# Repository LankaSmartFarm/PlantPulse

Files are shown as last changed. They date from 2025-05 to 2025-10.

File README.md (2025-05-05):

# 🌿 PlantPulse – Universal IoT Device for Smart Agriculture

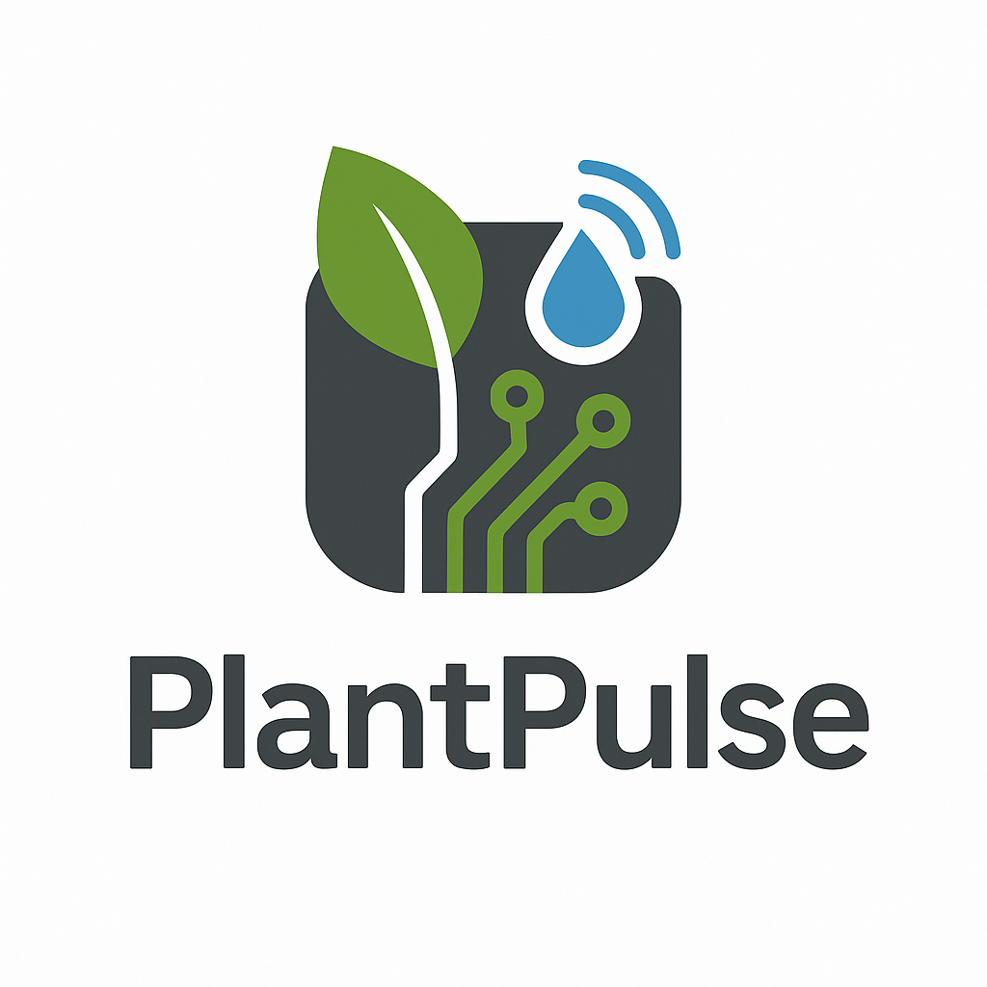
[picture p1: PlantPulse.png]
PlantPulse Logo


**PlantPulse** is an open-source, rugged, and intelligent IoT hardware platform designed as part of the LankaSmartFarm DPI initiative. It enables precision farming through sensor-driven insights and remote control, built specifically for the tropical agriculture challenges of Sri Lanka and similar regions.

This universal device combines sensing, communication, and control in a modular, scalable way—empowering farmers and AgriTech developers with real-time actionable data and automation.

---

## 🚀 Key Features

### 🌱 Sensor Suite (7-in-1 Soil Health Monitoring)
- Monitors:
  - **pH**
  - **Soil Moisture**
  - **Soil Temperature**
  - **Electrical Conductivity (EC)**
  - **Nitrogen (N)**
  - **Phosphorus (P)**
  - **Potassium (K)**  
- Periodic sensing powered by a separate 12V replaceable battery to preserve energy for critical reads.

### 🔊 Acoustic Monitoring & Alerting
- **Speaker + Microphone** for:
  - Insect repellent sound pulses
  - Audible alarms
  - Acoustic anomaly detection (under research)

### 🎯 Visual & Motion Sensing *(Research Stage)*
- Bug detection via visual traps
- Animal trespass monitoring using computer vision models or IR sensors

### 💧 Smart Irrigation & Fertigation Control
- Remotely control **drip irrigation** systems
- Activate **nutrient delivery** only when required

### 🔌 Controllable AUX & GPIO Ports
- Support for up to **10 auxiliary IOs**
- Configurable for lighting, spraying, fans, or custom actuators

---

## 🧠 Architecture

### 🌐 Central IoT Controller
- Acts as the **brain** of the PlantPulse network
- Connects to the cloud for telemetry reporting and receiving commands
- Commands child sensors dynamically—no need for hardcoded logic on each device
- Manages sensor behaviour and firmware updates centrally

### 📡 Child Sensor Nodes
- Connected via **RF or LoRa** for long-range, low-power communication
- Powered by:
  - **MCU battery** (rechargeable via compact solar panel array)
  - **12V sensing battery** for heavy sensor reads
- Contain **RGB status LEDs** for local feedback (alarm, status, fault, etc.)
- Built-in **self-check and debugging** capabilities to detect sensor connectivity or hardware faults

---

## 🛡️ Rugged Design

- **IP67-rated** enclosure
- Engineered to survive:
  - Tropical humidity
  - Heavy rainfall
  - High UV exposure
  - Impacts from falling fruits like coconuts or mangoes
- Can be securely fixed to the ground

---

## 🔧 Open Hardware Goals

PlantPulse aims to be:
- Fully **open-source** (hardware schematics + firmware)
- Modular and extensible
- Built using off-the-shelf components wherever possible
- Maintainable and upgradeable in the field with **no need for full reprogramming**

---

## 🌍 Why It Matters

- **Reduces manual labour and guesswork** in plantation and field farming
- **Supports climate-resilient agriculture** by providing precise micro-level insights
- **Scales easily** from backyard farms to large estates
- Aligns with **Digital Public Infrastructure (DPI)** and **DPG** principles

---

## 🧩 Project Status

- ✅ Hardware architecture and component design – In Progress  
- ⚙️ Firmware development – Early Stage  
- 📶 Communication protocol – RF/LoRa planned  
- 🔬 Bug and trespass detection – Research stage  
- 🔋 Solar & battery power testing – Prototyping  

Stay tuned for schematics, BOM, and reference firmware.

---

## 🤝 Contributing

We welcome hardware tinkerers, firmware developers, Agri researchers, and field testers.

Check our [CONTRIBUTING.md](CONTRIBUTING.md) to get started.

---

## 📜 License

This project will be released under an open hardware-compliant license (e.g., CERN-OHL or Solderpad License). Final terms TBA.

---

## 📬 Contact & Updates

- 🌐 [LankaSmartFarm GitHub](https://github.com/LankaSmartFarm)

---

> “Data grows when rooted in the soil. PlantPulse makes the invisible visible — one sensor at a time.”

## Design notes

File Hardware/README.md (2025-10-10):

# 🌿 Plant Pulse Hardware V1.0 (PCB)

### Featuring **ESP32-S3**

---

## 🧩 Overview
**Plant Pulse Hardware V1.0** is a custom-designed PCB built around the powerful **ESP32-S3** microcontroller.  
It is designed to monitor and analyze plant health and environmental conditions using advanced sensors and smart communication protocols.

---

## ⚙️ Key Features
- 🌱 **ESP32-S3** for Wi-Fi and Bluetooth connectivity  
- 🌾 **7-in-1 Soil Sensor Interface** for measuring multiple soil parameters  
- 🔄 **RS485 Modbus Communication** support for reliable industrial sensor interfacing  
- 🔋 **3.7V Li-ion Battery** operation for portable applications  
- 🔌 **USB Type-C Charging** for easy power management  

---

## 🔧 Hardware Highlights
| Component | Description |
|---|---|
| **MCU** | ESP32-S3 |
| **Sensor Interface** | 7-in-1 Soil Sensor via UART/RS485 |
| **Communication Protocol** | Modbus RTU |
| **Power Source** | 3.7V Li-ion Battery |
| **Charging Port** | USB Type-C |
| **Regulators & Protection** | Integrated battery protection and voltage regulation |

---

## 🪛 Applications
- Smart Agriculture 🌾  
- IoT-Based Plant Monitoring 🌿  
- Greenhouse Automation 🌼  
- Environmental Data Logging ☀️  

---

## 📘 Version Information
- **Version:** 1.0  
- **Type:** PCB Hardware Design  
- **Status:** Prototype/Testing Phase  

---

## 🧠 Future Improvements
- Onboard display (OLED/TFT) for real-time readings  
- Power optimization for long-term field deployment  

---

## 🖼️ Preview
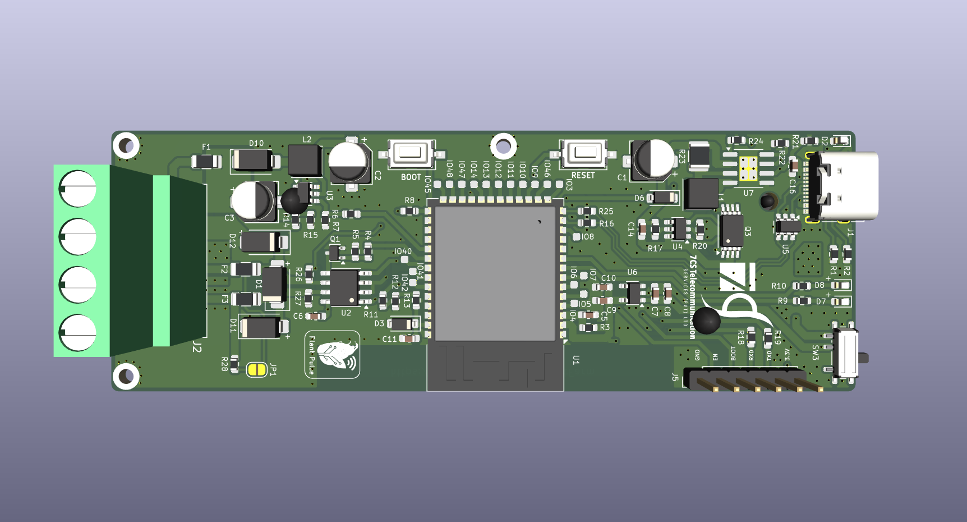
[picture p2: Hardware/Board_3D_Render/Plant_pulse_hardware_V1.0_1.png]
Plant Pulse PCB Top View

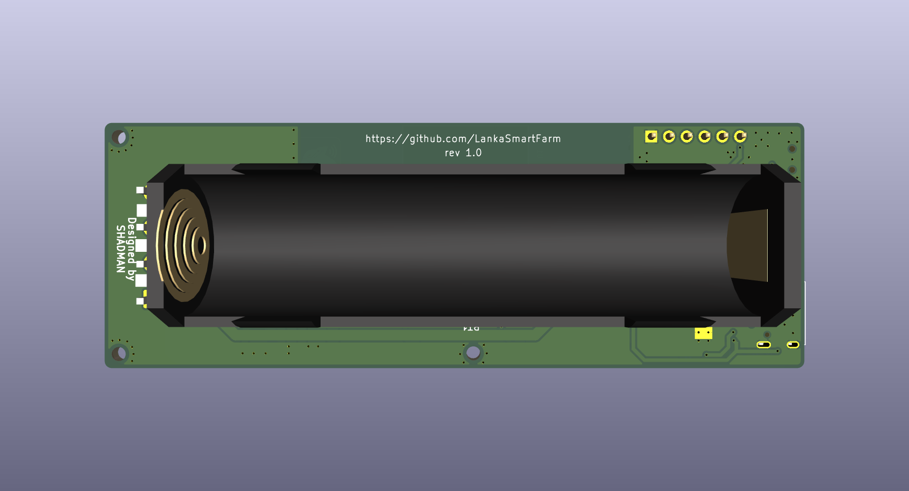
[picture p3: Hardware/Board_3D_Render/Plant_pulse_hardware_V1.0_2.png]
Plant Pulse PCB Bottom View

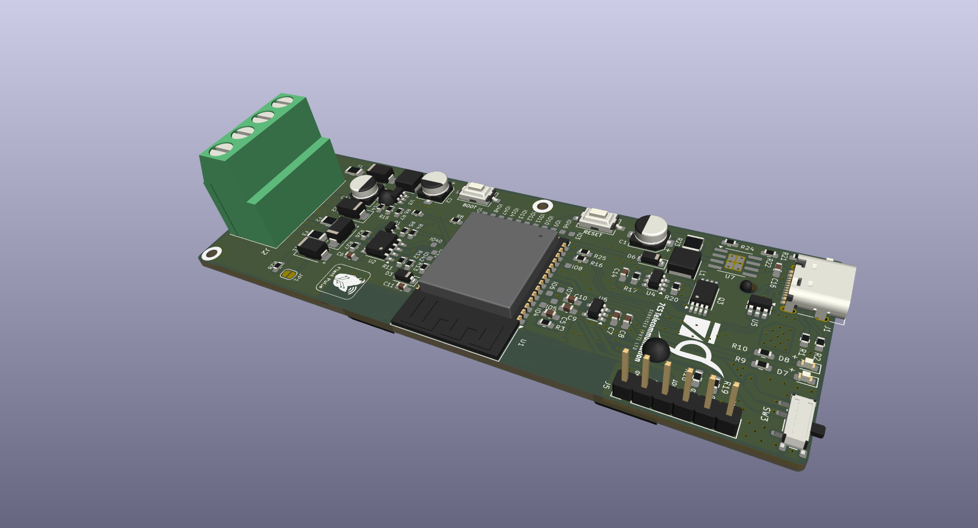
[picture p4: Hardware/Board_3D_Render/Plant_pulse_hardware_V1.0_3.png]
Plant Pulse PCB Side View

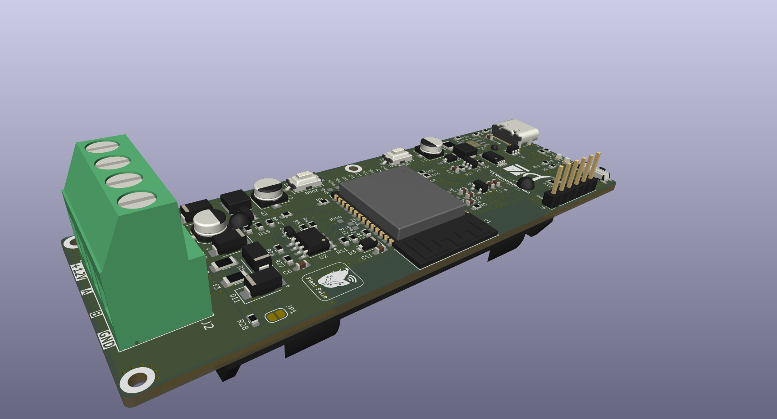
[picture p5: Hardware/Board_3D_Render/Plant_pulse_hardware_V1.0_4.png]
Plant Pulse PCB Side2 View


```bash
📁 /PlantPulse_Hardware_V1.0
 ├── Gerber_Files/
 ├── Schematic PDF/
 ├── Board_3D_Render
 ├── BOM_POS/
 └── README.md

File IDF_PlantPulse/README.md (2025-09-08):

# 🌱 PlantPulse – Smart Agriculture Monitoring System  

PlantPulse is an **ESP32-based IoT device** for precision agriculture.  
It collects data from **20 Modbus soil sensors** (pH, moisture, temperature, EC, N, P, K), logs it into **FATFS**, synchronizes time with a **DS3231 RTC** and GSM network, and transmits data to the cloud over **SIM800L MQTT**.

---

## 🚀 Features  
- 📡 **MQTT over SIM800L GSM** (custom lightweight MQTT client)  
- 🧪 **20 Soil Sensors** via RS485 Modbus  
- 🕒 **Timekeeping with DS3231 RTC** (synced with GSM time if drift >10s)  
- 💾 **Data Logging with FATFS** (binary files, timestamped filenames)  
- 🔄 **Auto Reconnect** for GSM & MQTT  
- 🗑️ **Reliable Storage** – if publish fails, payload is stored in FATFS and re-sent later  
- 🔌 **Custom ESP-IDF Components** (MQTT, RTC, RS485, FATFS)  

---

## 🔌 Hardware Pinout  

| Peripheral | ESP32 Pin | Notes |
|---|---|---|
| **SIM800L GSM** | | |
| TX (SIM800L → ESP32 RX) | GPIO15 | UART1 RX (ESP32 receives) |
| RX (SIM800L ← ESP32 TX) | GPIO16 | UART1 TX (ESP32 transmits) |
| RESET | GPIO3 | SIM800L reset control |
| **RTC DS3231** | | |
| I2C SDA | GPIO4 | I2C data line |
| I2C SCL | GPIO5 | I2C clock line |
| INT/SQW | GPIO6 | RTC interrupt / square wave output  |
| **RS485 Modbus** | | |
| RX | GPIO17 | UART RX for Modbus slave |
| TX | GPIO18 | UART TX for Modbus master |

*(Update pins as per your final design)*  

---

## 📡 Protocols  

- **MQTT (Custom Lightweight Client over GSM AT commands)**  
- **Modbus RTU** (RS485 multi-drop for soil sensors)  
- **FATFS** (SPI Flash storage for logs & credentials)  
- **I2C** (RTC DS3231 time sync)  

---

## 📂 File Structure  

├── components/ # Custom ESP-IDF components
│ ├── mqtt/ # SIM800L MQTT client
│ ├── myRtc/ # DS3231 RTC driver
│ └── RS_485/ # Modbus RS485 driver
├── main/ # Application code
│ ├── storage/ # FATFS storage handling
│ │ ├── FS.c
│ │ └── FS.h
│ ├── dataLogging.c # Logging logic
│ ├── dataLogging.h
│ ├── main.c # Main application entry point
│ └── CMakeLists.txt
├── partitions.csv # Flash partition table
├── CMakeLists.txt # Project CMake

---

## ⚡ Build & Flash Instructions  

```bash
# Clone repo
git clone https://github.com/yourusername/PlantPulse.git
cd PlantPulse

# Set ESP-IDF environment
. $HOME/esp/esp-idf/export.sh

# Build
idf.py build

# Flash
idf.py -p /dev/ttyUSB0 flash

# Monitor
idf.py monitor

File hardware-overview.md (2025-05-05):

# 🔩 PlantPulse Hardware Overview

This document outlines the hardware architecture and component design of the **PlantPulse** universal smart farming IoT device.

---

## 📦 System Architecture

### 🧠 Central IoT Controller

- **Role**: Central command unit for all child sensor nodes
- **Responsibilities**:
  - Connects to the cloud (Wi-Fi/4G/LTE)
  - Receives commands from cloud services
  - Sends telemetry data (sensor readings, device health)
  - Dispatches control signals to child sensor nodes
- **Features**:
  - Local command queuing and scheduling
  - Minimal power consumption with sleep cycles
  - Modular firmware upgradable remotely

### 🌿 Child Sensor Nodes (Field Units)

- **Communication**: RF/LoRa modules (up to 1–2 km LOS)
- **Power System**:
  - Rechargeable battery (MCU operation)
  - 12V replaceable battery (for 7-in-1 sensing only)
  - Solar charging system (4x calculator-sized panels)
- **Indicators**: RGB LED for:
  - Alarms
  - Sensor health
  - Activity indication
- **Self-diagnostics**: Sensor connection and health checks

---

## 🧪 Sensor Suite

### 🔬 7-in-1 Soil Quality Sensor

- pH
- Soil Moisture
- Soil Temperature
- Electrical Conductivity (EC)
- Nitrogen (N)
- Phosphorus (P)
- Potassium (K)

### 🔊 Acoustic Subsystem

- **Microphone**: Insect detection, environmental sound capture
- **Speaker**: Alarm output, sound-based repellent (experimental)

### 👀 Visual Detection *(Under Research)*

- Bug trap imaging and recognition
- Animal trespass detection using camera module + CV

---

## 🔌 AUX & GPIO Expansion

- **Up to 10 GPIOs** for:
  - Relays
  - Pumps
  - Lights
  - External devices
- Fully configurable via central controller commands

---

## 🛡️ Enclosure & Protection

- **IP67-rated** shell
- Designed to resist:
  - Rain, humidity, and heat
  - Impact from falling fruits (e.g., coconuts, mangoes)
  - Ground vibrations and animals
- Ground-anchorable

---

## 🧩 Component Sourcing

- Off-the-shelf modules where possible
- Open schematics and BOM to be published

---

## 🗺️ Deployment Topologies

- **Standalone Node**: Single unit operation for isolated crops
- **Cluster Mode**: One central controller managing up to 50+ nodes
- **Mesh Expansion**: Planned support for mesh networking in Phase 2

---

> Want to help with circuit design or PCB layout? Start a discussion or open an issue!

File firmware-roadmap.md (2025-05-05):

# 🧠 PlantPulse Firmware Roadmap

This document outlines the development plan for firmware modules across the PlantPulse IoT system.

---

## 🏗️ Architecture

### Firmware Layers:

1. **Device Abstraction Layer (DAL)**  
   - Interfaces directly with sensors, IOs, and power modules

2. **Control Logic Layer**  
   - Executes scheduled actions
   - Interprets central controller commands
   - Handles local events and diagnostics

3. **Communication Layer**  
   - RF/LoRa communication protocol
   - Data encryption & compression
   - OTA firmware update protocol (planned)

4. **Telemetry Layer**  
   - Formats and sends telemetry to central controller
   - Includes timestamps, battery, sensor data, and faults

---

## 📅 Roadmap

### 🔹 Phase 1 – MVP (Q2 2025)
- [x] Basic GPIO toggling from central controller
- [x] Periodic sensor reading
- [x] RGB LED status indicators
- [ ] Basic telemetry reporting
- [ ] Manual reset + debug mode

### 🔸 Phase 2 – Core Features (Q3 2025)
- [ ] LoRa mesh node discovery
- [ ] Event-driven triggers (e.g., moisture too low → activate pump)
- [ ] OTA firmware updates
- [ ] Self-diagnostics on sensor health

### 🔹 Phase 3 – Advanced Intelligence (Q4 2025)
- [ ] AI-assisted edge logic (soil condition learning)
- [ ] Audio event pattern detection
- [ ] Vision-based bug/animal detection (if module available)

---

## 🛠 Development Notes

- Written in C/C++ (Arduino/PlatformIO base)
- Open to MicroPython and Rust prototypes
- GitHub Actions CI for unit testing
- Separate branches for stable vs. experimental firmware

---

> Contributions welcome for modular drivers, LoRa protocol enhancements, or data compression techniques.

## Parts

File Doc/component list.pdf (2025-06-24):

## List of Components

SN | Name | Quantity
1 | ESP32-S3 N16R8 | 2
2 | TTL to RS-485 | 2
3 | 7in 1 Sensor | 2
4 | USB Type-C Cable | 2
5 | USB to RS-485 Converter | 1
6 | 12V Battery pack | 1
7 | Lora( SX1278)+ Atenna | 2
8 | GSM Module SIM800L or SIM800C | 1
9 | Antenna | 2
10 | Buck Converter | 3
11 | Led Multiple Color | 20
12 | Power Supply 12v | 1
13 | Some wire | As needed
14 | Male/Female jumper wire (good Quality) | As needed
15 | Power Switch | 3
16 | 4 Chanel Relay | 2
17 | DS1307 RTC module | 1
18 | RTC Battery | 2
19 | Glugan, glustic | 1
20 | Bero board | 3
21 | Male Header | As needed
22 | Resistor | 1k, 330, 10k
23 | Push Button Switch | 5

2 4 | C a p a cit o r | 1 0, 2 0, 5 0, 1 5,1 0 0 m
| Insulation tape Plastic box | 1 26 To keep all materials f, 25

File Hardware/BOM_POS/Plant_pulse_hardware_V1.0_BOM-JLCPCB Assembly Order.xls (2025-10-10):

JLCPCB BOM Tool - BOM Matching
BOM name：Plant_pulse_hardware_V1.0_BOM-JLCPCB Assembly Order.xlsx |  |  | Download Time：2025-10-04 22:56:29 |  |  |  | * Our matching results are updated in real-time, but stock and prices may change. If it's been over 24 hours, please re-match before placing your order.
PCB Assembled Qty：10 |  |  | Est. Total Price：28.1363
Your BOM |  |  |  |  | Matched Parts |  |  |  |  |  |  | Order Information
Top Designator | Bottom Designator | Comment | Footprint | JLCPCB Part # | Matches | Part # | Manufacturer | Footprint | Description | Category | Warning | JLCPCB Part # | Product link | Lib Type | Qty | Source | Total Price ($)
C1 |  | 220uf/35V | Capacitor_SMD:CP_Elec_5x3 |  | Select by System | RVT1C220M0505 22UF 16V | DMBJ | SMD,D5xL5.4mm | -55℃~+105℃ 16V 22uF 2800hrs@105℃ 28mA@120Hz 5.4mm 5mm ±20% SMD,D5xL5.4mm Aluminum Electrolytic Capacitors - SMD ROHS | Aluminum Electrolytic Capacitors - SMD |  | C970662 | https://jlcpcb.com/partdetail/DMBJ-RVT1C220M0505_22UF16V/C970662 | Extended | 34 | 34 JLCPCB | 0.9452
C2 |  | 220uf/35V | Capacitor_SMD:CP_Elec_5x3 |  | Select by System | RVT1C220M0505 22UF 16V | DMBJ | SMD,D5xL5.4mm | -55℃~+105℃ 16V 22uF 2800hrs@105℃ 28mA@120Hz 5.4mm 5mm ±20% SMD,D5xL5.4mm Aluminum Electrolytic Capacitors - SMD ROHS | Aluminum Electrolytic Capacitors - SMD |  | C970662 | https://jlcpcb.com/partdetail/DMBJ-RVT1C220M0505_22UF16V/C970662 | Extended | 34 | 34 JLCPCB | 0.9452
C3 |  | 220uf/35V | Capacitor_SMD:CP_Elec_5x3 |  | Select by System | RVT1C220M0505 22UF 16V | DMBJ | SMD,D5xL5.4mm | -55℃~+105℃ 16V 22uF 2800hrs@105℃ 28mA@120Hz 5.4mm 5mm ±20% SMD,D5xL5.4mm Aluminum Electrolytic Capacitors - SMD ROHS | Aluminum Electrolytic Capacitors - SMD |  | C970662 | https://jlcpcb.com/partdetail/DMBJ-RVT1C220M0505_22UF16V/C970662 | Extended | 34 | 34 JLCPCB | 0.9452
C5 |  | 1uf/16V | Capacitor_SMD:C_0603_1608Metric_Pad1.08x0.95mm_HandSolder |  | Select by System | CL10A105KB8NNNC | Samsung Electro-Mechanics | 0603 | 1uF 50V X5R ±10% 0603 Multilayer Ceramic Capacitors MLCC - SMD/SMT ROHS | Multilayer Ceramic Capacitors MLCC - SMD/SMT |  | C15849 | https://jlcpcb.com/partdetail/16531-CL10A105KB8NNNC/C15849 | Basic | 10 | 10 JLCPCB | 0.047
C6 |  | 100nf/50V | Capacitor_SMD:C_0603_1608Metric_Pad1.08x0.95mm_HandSolder |  | Select by System | CC0603KRX7R9BB104 | YAGEO | 0603 | 100nF 50V X7R ±10% 0603 Multilayer Ceramic Capacitors MLCC - SMD/SMT ROHS | Multilayer Ceramic Capacitors MLCC - SMD/SMT |  | C14663 | https://jlcpcb.com/partdetail/YAGEO-CC0603KRX7R9BB104/C14663 | Basic | 50 | 50 JLCPCB | 0.115
C8 |  | 100nf/50V | Capacitor_SMD:C_0603_1608Metric_Pad1.08x0.95mm_HandSolder |  | Select by System | CC0603KRX7R9BB104 | YAGEO | 0603 | 100nF 50V X7R ±10% 0603 Multilayer Ceramic Capacitors MLCC - SMD/SMT ROHS | Multilayer Ceramic Capacitors MLCC - SMD/SMT |  | C14663 | https://jlcpcb.com/partdetail/YAGEO-CC0603KRX7R9BB104/C14663 | Basic | 50 | 50 JLCPCB | 0.115
C9 |  | 100nf/50V | Capacitor_SMD:C_0603_1608Metric_Pad1.08x0.95mm_HandSolder |  | Select by System | CC0603KRX7R9BB104 | YAGEO | 0603 | 100nF 50V X7R ±10% 0603 Multilayer Ceramic Capacitors MLCC - SMD/SMT ROHS | Multilayer Ceramic Capacitors MLCC - SMD/SMT |  | C14663 | https://jlcpcb.com/partdetail/YAGEO-CC0603KRX7R9BB104/C14663 | Basic | 50 | 50 JLCPCB | 0.115
C11 |  | 100nf/50V | Capacitor_SMD:C_0603_1608Metric_Pad1.08x0.95mm_HandSolder |  | Select by System | CC0603KRX7R9BB104 | YAGEO | 0603 | 100nF 50V X7R ±10% 0603 Multilayer Ceramic Capacitors MLCC - SMD/SMT ROHS | Multilayer Ceramic Capacitors MLCC - SMD/SMT |  | C14663 | https://jlcpcb.com/partdetail/YAGEO-CC0603KRX7R9BB104/C14663 | Basic | 50 | 50 JLCPCB | 0.115
C14 |  | 100nf/50V | Capacitor_SMD:C_0603_1608Metric_Pad1.08x0.95mm_HandSolder |  | Select by System | CC0603KRX7R9BB104 | YAGEO | 0603 | 100nF 50V X7R ±10% 0603 Multilayer Ceramic Capacitors MLCC - SMD/SMT ROHS | Multilayer Ceramic Capacitors MLCC - SMD/SMT |  | C14663 | https://jlcpcb.com/partdetail/YAGEO-CC0603KRX7R9BB104/C14663 | Basic | 50 | 50 JLCPCB | 0.115
C7 |  | 10uf/50V | Capacitor_SMD:C_0603_1608Metric_Pad1.08x0.95mm_HandSolder |  | Select by Customer | CL10A106KP8NNNC | Samsung Electro-Mechanics | 0603 | 10V 10uF X5R ±10% 0603 Multilayer Ceramic Capacitors MLCC - SMD/SMT ROHS | Multilayer Ceramic Capacitors MLCC - SMD/SMT |  | C19702 | https://jlcpcb.com/partdetail/20411-CL10A106KP8NNNC/C19702 | Basic | 30 | 30 JLCPCB | 0.168
C10 |  | 10uf/50V | Capacitor_SMD:C_0603_1608Metric_Pad1.08x0.95mm_HandSolder |  | Select by Customer | CL10A106KP8NNNC | Samsung Electro-Mechanics | 0603 | 10V 10uF X5R ±10% 0603 Multilayer Ceramic Capacitors MLCC - SMD/SMT ROHS | Multilayer Ceramic Capacitors MLCC - SMD/SMT |  | C19702 | https://jlcpcb.com/partdetail/20411-CL10A106KP8NNNC/C19702 | Basic | 30 | 30 JLCPCB | 0.168
C16 |  | 10uf/50V | Capacitor_SMD:C_0603_1608Metric_Pad1.08x0.95mm_HandSolder |  | Select by Customer | CL10A106KP8NNNC | Samsung Electro-Mechanics | 0603 | 10V 10uF X5R ±10% 0603 Multilayer Ceramic Capacitors MLCC - SMD/SMT ROHS | Multilayer Ceramic Capacitors MLCC - SMD/SMT |  | C19702 | https://jlcpcb.com/partdetail/20411-CL10A106KP8NNNC/C19702 | Basic | 30 | 30 JLCPCB | 0.168
D1 |  | SMAJ6.8CA | Diode_SMD:D_SMA |  | Select by System | SMAJ6.8CA | FUXINSEMI | DO-214AC(SMA) | 10.5V 1mA 39A 400W 5.8V 7.14V Bidirectional TVS DO-214AC(SMA) ESD and Surge Protection (TVS/ESD) ROHS | ESD And Surge Protection (TVS/ESD) |  | C5380696 | https://jlcpcb.com/partdetail/FUXINSEMI-SMAJ68CA/C5380696 | Extended | 38 | 38 JLCPCB | 1.2198
D11 |  | SMAJ6.8CA | Diode_SMD:D_SMA |  | Select by System | SMAJ6.8CA | FUXINSEMI | DO-214AC(SMA) | 10.5V 1mA 39A 400W 5.8V 7.14V Bidirectional TVS DO-214AC(SMA) ESD and Surge Protection (TVS/ESD) ROHS | ESD And Surge Protection (TVS/ESD) |  | C5380696 | https://jlcpcb.com/partdetail/FUXINSEMI-SMAJ68CA/C5380696 | Extended | 38 | 38 JLCPCB | 1.2198
D12 |  | SMAJ6.8CA | Diode_SMD:D_SMA |  | Select by System | SMAJ6.8CA | FUXINSEMI | DO-214AC(SMA) | 10.5V 1mA 39A 400W 5.8V 7.14V Bidirectional TVS DO-214AC(SMA) ESD and Surge Protection (TVS/ESD) ROHS | ESD And Surge Protection (TVS/ESD) |  | C5380696 | https://jlcpcb.com/partdetail/FUXINSEMI-SMAJ68CA/C5380696 | Extended | 38 | 38 JLCPCB | 1.2198
D2 |  | LED_RED | LED_SMD:LED_0603_1608Metric |  | Select by System | YLED0805R | YONGYUTAI | 0805 | -40℃~+85℃ 1.8V~2.4V 120mcd 120° 20mA 60mW 615nm~630nm 645nm Red 0805 LED Indication - Discrete ROHS | LED Indication - Discrete |  | C19171391 | https://jlcpcb.com/partdetail/YONGYUTAI-YLED0805R/C19171391 | Extended | 20 | 20 JLCPCB | 0.142
D6 |  | 1N4148W | Diode_SMD:D_SOD-123 |  | Select by System | 1N4148W-7-F | Diodes Incorporated | SOD-123 | -65℃~+150℃@(Tj) 1.25V@150mA 100V 1uA@75V 300mA 4ns Independent SOD-123 Switching Diodes ROHS | Switching Diodes |  | C83528 | https://jlcpcb.com/partdetail/DiodesIncorporated-1N4148W_7F/C83528 | Extended | 20 | 20 JLCPCB | 0.31
D7 |  | LED_GERRN | LED_SMD:LED_0603_1608Metric |  | Unconfirmed | KT-0603R | Hubei KENTO Elec | 0603 | -40℃~+85℃ 120° 2.4V 20mA 300mcd 40mW 615nm~630nm 645nm Red Water Clear 0603 LED Indication - Discrete ROHS | LED Indication - Discrete | 1.The comment (KT-0603R) of this part does not match the one (LED_GERRN) provided in your BOM. Please confirm; | C2286 | https://jlcpcb.com/partdetail/Hubei_KENTOElec-KT0603R/C2286 | Basic | 0 | 0 JLCPCB | 0
D8 |  | LED_BLUE | LED_SMD:LED_0603_1608Metric |  | Select by System | LTST-C191TBKT | Lite-On | 0603 | -20℃~+80℃ 104mcd 130° 20mA 3.3V 465nm~475nm 468nm 75mW Blue Water Clear 0603 LED Indication - Discrete ROHS | LED Indication - Discrete |  | C99290 | https://jlcpcb.com/partdetail/LiteOn-LTSTC191TBKT/C99290 | Extended | 20 | 20 JLCPCB | 0.382
D9 |  | BZM55B3V3-TR | Diode_SMD:D_MicroMELF |  | Select by Customer | ZMM3V3 | Slkor(SLKORMICRO Elec.) | LL-34 | 2uA 3.1V~3.5V 3.3V 500mW 600Ω 85Ω Independent LL-34 Zener Diodes ROHS | Zener Diodes |  | C707189 | https://jlcpcb.com/partdetail/Slkor_SLKORMICRO_Elec-ZMM3V3/C707189 | Extended | 20 | 20 JLCPCB | 0.174
D10 |  | SS34 | Diode_SMD:D_SMA |  | Select by System | SS34 | MDD(Microdiode Semiconductor) | SMA(DO-214AC) | -55℃~+125℃ 3A 40V 500uA@40V 550mV@3A Independent SMA(DO-214AC) Schottky Diodes ROHS | Schottky Diodes |  | C8678 | https://jlcpcb.com/partdetail/MDD_Microdiode_Semiconductor-SS34/C8678 | Basic | 10 | 10 JLCPCB | 0.276
F1 |  | 0468001.NRHF | Fuse:Fuse_1206_3216Metric |  | Select by System | 0468001.NRHF | Littelfuse | 1206 | -55℃~+90℃ 1A 50A 63V Surface Mount Fuse 1206 Disposable fuses ROHS | Disposable Fuses |  | C45157 | https://jlcpcb.com/partdetail/Littelfuse-0468001NRHF/C45157 | Extended | 12 | 12 JLCPCB | 0.756
F2 |  | BSMD1206C-0250T | Fuse:Fuse_1206_3216Metric |  | Select by System | BSMD1206C-0250T | BHFUSE | 1206 | -55℃~+150℃ 0.00043 250mA 50A 72V 72V Surface Mount Fuse 1206 Disposable fuses ROHS | Disposable Fuses |  | C41398508 | https://jlcpcb.com/partdetail/BHFUSE-BSMD1206C0250T/C41398508 | Extended | 24 | 24 JLCPCB | 1.8768
F3 |  | BSMD1206C-0250T | Fuse:Fuse_1206_3216Metric |  | Select by System | BSMD1206C-0250T | BHFUSE | 1206 | -55℃~+150℃ 0.00043 250mA 50A 72V 72V Surface Mount Fuse 1206 Disposable fuses ROHS | Disposable Fuses |  | C41398508 | https://jlcpcb.com/partdetail/BHFUSE-BSMD1206C0250T/C41398508 | Extended | 24 | 24 JLCPCB | 1.8768
J1 |  | USB_C_Receptacle_USB2.0_16P | Connector_USB:USB_C_Receptacle_G-Switch_GT-USB-7010ASV |  | Select by System | TYPE-C 16PIN 2MD(073) | SHOU HAN | SMD | -25℃~+85℃ 1 16P 3A 5,000 Cycles 5V Black Female Surface Mount, Right Angle Type-C SMD USB Connectors ROHS | USB Connectors |  | C2765186 | https://jlcpcb.com/partdetail/SHOUHAN-TYPE_C_16PIN_2MD_073/C2765186 | Extended | 11 | 11 JLCPCB | 0.6193
L1 |  | 4.7uh | Inductor_SMD:L_Changjiang_FNR4020S |  | Select by System | FNR4020S4R7MT | cjiang (Changjiang Microelectronics Tech) | SMD,4x4mm | 2.5A 2A 4.7uH 98mΩ Magnetic Shielded Inductor ±20% SMD,4x4mm Power Inductors ROHS | Power Inductors |  | C167828 | https://jlcpcb.com/partdetail/179211-FNR4020S4R7MT/C167828 | Extended | 24 | 24 JLCPCB | 1.1352
L2 |  | 4.7uh | Inductor_SMD:L_Changjiang_FNR4020S |  | Select by System | FNR4020S4R7MT | cjiang (Changjiang Microelectronics Tech) | SMD,4x4mm | 2.5A 2A 4.7uH 98mΩ Magnetic Shielded Inductor ±20% SMD,4x4mm Power Inductors ROHS | Power Inductors |  | C167828 | https://jlcpcb.com/partdetail/179211-FNR4020S4R7MT/C167828 | Extended | 24 | 24 JLCPCB | 1.1352
Q1 |  | Si1308EDL | Package_TO_SOT_SMD:SOT-323_SC-70 |  | Select by System | SI1308EDL | TECH PUBLIC | SOT-323 | -55℃~+150℃ 1.4A 1.5V 14.8pF@15V 146pF@15V 150mΩ@4.5V,0.5A 30V 360mW SOT-323 MOSFETs ROHS | MOSFETs |  | C7603347 | https://jlcpcb.com/partdetail/TECHPUBLIC-SI1308EDL/C7603347 | Extended | 14 | 14 JLCPCB | 0.8274
Q3 |  | FS8205A | Package_SO:TSSOP-8_4.4x3mm_P0.65mm |  | Select by System | 8205A | HXY MOSFET | TSSOP-8 | -55℃~+150℃ 1.5W 140pF 15nC@4.5V 2 N-Channel 20V 37mΩ@2.5V,3.5A 500mV 600pF 6A TSSOP-8 MOSFETs ROHS | MOSFETs |  | C5148694 | https://jlcpcb.com/partdetail/HXYMOSFET-8205A/C5148694 | Extended | 14 | 14 JLCPCB | 0.756
R1 |  | 5.1K | Resistor_SMD:R_0603_1608Metric |  | Unconfirmed | 0603WAF5101T5E | UNI-ROYAL(Uniroyal Elec) | 0603 | -55℃~+155℃ 100mW 5.1kΩ 75V Thick Film Resistor ±1% ±100ppm/℃ 0603 Chip Resistor - Surface Mount ROHS | Chip Resistor - Surface Mount | 1.The comment (0603WAF5101T5E) of this part does not match the one (5.1K) provided in your BOM. Please confirm; | C23186 | https://jlcpcb.com/partdetail/23913-0603WAF5101T5E/C23186 | Basic | 0 | 0 JLCPCB | 0
R2 |  | 5.1K | Resistor_SMD:R_0603_1608Metric |  | Unconfirmed | 0603WAF5101T5E | UNI-ROYAL(Uniroyal Elec) | 0603 | -55℃~+155℃ 100mW 5.1kΩ 75V Thick Film Resistor ±1% ±100ppm/℃ 0603 Chip Resistor - Surface Mount ROHS | Chip Resistor - Surface Mount | 1.The comment (0603WAF5101T5E) of this part does not match the one (5.1K) provided in your BOM. Please confirm; | C23186 | https://jlcpcb.com/partdetail/23913-0603WAF5101T5E/C23186 | Basic | 0 | 0 JLCPCB | 0
R9 |  | 5.1K | Resistor_SMD:R_0603_1608Metric |  | Unconfirmed | 0603WAF5101T5E | UNI-ROYAL(Uniroyal Elec) | 0603 | -55℃~+155℃ 100mW 5.1kΩ 75V Thick Film Resistor ±1% ±100ppm/℃ 0603 Chip Resistor - Surface Mount ROHS | Chip Resistor - Surface Mount | 1.The comment (0603WAF5101T5E) of this part does not match the one (5.1K) provided in your BOM. Please confirm; | C23186 | https://jlcpcb.com/partdetail/23913-0603WAF5101T5E/C23186 | Basic | 0 | 0 JLCPCB | 0
R10 |  | 5.1K | Resistor_SMD:R_0603_1608Metric |  | Unconfirmed | 0603WAF5101T5E | UNI-ROYAL(Uniroyal Elec) | 0603 | -55℃~+155℃ 100mW 5.1kΩ 75V Thick Film Resistor ±1% ±100ppm/℃ 0603 Chip Resistor - Surface Mount ROHS | Chip Resistor - Surface Mount | 1.The comment (0603WAF5101T5E) of this part does not match the one (5.1K) provided in your BOM. Please confirm; | C23186 | https://jlcpcb.com/partdetail/23913-0603WAF5101T5E/C23186 | Basic | 0 | 0 JLCPCB | 0
R3 |  | 10K | Resistor_SMD:R_0603_1608Metric |  | Unconfirmed | 0603WAF1002T5E | UNI-ROYAL(Uniroyal Elec) | 0603 | -55℃~+155℃ 100mW 10kΩ 75V Thick Film Resistor ±1% ±100ppm/℃ 0603 Chip Resistor - Surface Mount ROHS | Chip Resistor - Surface Mount | 1.The comment (0603WAF1002T5E) of this part does not match the one (10K) provided in your BOM. Please confirm; | C25804 | https://jlcpcb.com/partdetail/26547-0603WAF1002T5E/C25804 | Basic | 0 | 0 JLCPCB | 0
R7 |  | 10K | Resistor_SMD:R_0603_1608Metric |  | Unconfirmed | 0603WAF1002T5E | UNI-ROYAL(Uniroyal Elec) | 0603 | -55℃~+155℃ 100mW 10kΩ 75V Thick Film Resistor ±1% ±100ppm/℃ 0603 Chip Resistor - Surface Mount ROHS | Chip Resistor - Surface Mount | 1.The comment (0603WAF1002T5E) of this part does not match the one (10K) provided in your BOM. Please confirm; | C25804 | https://jlcpcb.com/partdetail/26547-0603WAF1002T5E/C25804 | Basic | 0 | 0 JLCPCB | 0
R12 |  | 10K | Resistor_SMD:R_0603_1608Metric |  | Unconfirmed | 0603WAF1002T5E | UNI-ROYAL(Uniroyal Elec) | 0603 | -55℃~+155℃ 100mW 10kΩ 75V Thick Film Resistor ±1% ±100ppm/℃ 0603 Chip Resistor - Surface Mount ROHS | Chip Resistor - Surface Mount | 1.The comment (0603WAF1002T5E) of this part does not match the one (10K) provided in your BOM. Please confirm; | C25804 | https://jlcpcb.com/partdetail/26547-0603WAF1002T5E/C25804 | Basic | 0 | 0 JLCPCB | 0
R24 |  | 10K | Resistor_SMD:R_0603_1608Metric |  | Unconfirmed | 0603WAF1002T5E | UNI-ROYAL(Uniroyal Elec) | 0603 | -55℃~+155℃ 100mW 10kΩ 75V Thick Film Resistor ±1% ±100ppm/℃ 0603 Chip Resistor - Surface Mount ROHS | Chip Resistor - Surface Mount | 1.The comment (0603WAF1002T5E) of this part does not match the one (10K) provided in your BOM. Please confirm; | C25804 | https://jlcpcb.com/partdetail/26547-0603WAF1002T5E/C25804 | Basic | 0 | 0 JLCPCB | 0
R4 |  | 12K | Resistor_SMD:R_0603_1608Metric |  | Unconfirmed | 0603WAF1202T5E | UNI-ROYAL(Uniroyal Elec) | 0603 | -55℃~+155℃ 100mW 12kΩ 75V Thick Film Resistor ±1% ±100ppm/℃ 0603 Chip Resistor - Surface Mount ROHS | Chip Resistor - Surface Mount | 1.The comment (0603WAF1202T5E) of this part does not match the one (12K) provided in your BOM. Please confirm; | C22790 | https://jlcpcb.com/partdetail/23517-0603WAF1202T5E/C22790 | Basic | 0 | 0 JLCPCB | 0
R5 |  | 47K | Resistor_SMD:R_0603_1608Metric |  | Unconfirmed | 0603WAF4702T5E | UNI-ROYAL(Uniroyal Elec) | 0603 | -55℃~+155℃ 100mW 47kΩ 75V Thick Film Resistor ±1% ±100ppm/℃ 0603 Chip Resistor - Surface Mount ROHS | Chip Resistor - Surface Mount | 1.The comment (0603WAF4702T5E) of this part does not match the one (47K) provided in your BOM. Please confirm; | C25819 | https://jlcpcb.com/partdetail/26562-0603WAF4702T5E/C25819 | Basic | 0 | 0 JLCPCB | 0
R6 |  | 1K | Resistor_SMD:R_0603_1608Metric |  | Unconfirmed | 0603WAF1001T5E | UNI-ROYAL(Uniroyal Elec) | 0603 | -55℃~+155℃ 100mW 1kΩ 75V Thick Film Resistor ±1% ±100ppm/℃ 0603 Chip Resistor - Surface Mount ROHS | Chip Resistor - Surface Mount | 1.The comment (0603WAF1001T5E) of this part does not match the one (1K) provided in your BOM. Please confirm; 2.Multiple lines in the BOM have been matched to the same part. Please check if the matching is correct. ; | C21190 | https://jlcpcb.com/partdetail/21904-0603WAF1001T5E/C21190 | Basic | 0 | 0 JLCPCB | 0
R13 |  | 1K | Resistor_SMD:R_0603_1608Metric |  | Unconfirmed | 0603WAF1001T5E | UNI-ROYAL(Uniroyal Elec) | 0603 | -55℃~+155℃ 100mW 1kΩ 75V Thick Film Resistor ±1% ±100ppm/℃ 0603 Chip Resistor - Surface Mount ROHS | Chip Resistor - Surface Mount | 1.The comment (0603WAF1001T5E) of this part does not match the one (1K) provided in your BOM. Please confirm; 2.Multiple lines in the BOM have been matched to the same part. Please check if the matching is correct. ; | C21190 | https://jlcpcb.com/partdetail/21904-0603WAF1001T5E/C21190 | Basic | 0 | 0 JLCPCB | 0
R20 |  | 1K | Resistor_SMD:R_0603_1608Metric_Pad0.98x0.95mm_HandSolder |  | Unconfirmed | 0603WAF1001T5E | UNI-ROYAL(Uniroyal Elec) | 0603 | -55℃~+155℃ 100mW 1kΩ 75V Thick Film Resistor ±1% ±100ppm/℃ 0603 Chip Resistor - Surface Mount ROHS | Chip Resistor - Surface Mount | 1.The comment (0603WAF1001T5E) of this part does not match the one (1K) provided in your BOM. Please confirm; 2.Multiple lines in the BOM have been matched to the same part. Please check if the matching is correct. ; | C21190 | https://jlcpcb.com/partdetail/21904-0603WAF1001T5E/C21190 | Basic | 0 | 0 JLCPCB | 0
R21 |  | 1K | Resistor_SMD:R_0603_1608Metric |  | Unconfirmed | 0603WAF1001T5E | UNI-ROYAL(Uniroyal Elec) | 0603 | -55℃~+155℃ 100mW 1kΩ 75V Thick Film Resistor ±1% ±100ppm/℃ 0603 Chip Resistor - Surface Mount ROHS | Chip Resistor - Surface Mount | 1.The comment (0603WAF1001T5E) of this part does not match the one (1K) provided in your BOM. Please confirm; 2.Multiple lines in the BOM have been matched to the same part. Please check if the matching is correct. ; | C21190 | https://jlcpcb.com/partdetail/21904-0603WAF1001T5E/C21190 | Basic | 0 | 0 JLCPCB | 0
R11 |  | 100K | Resistor_SMD:R_0603_1608Metric |  | Unconfirmed | 0603WAF1003T5E | UNI-ROYAL(Uniroyal Elec) | 0603 | -55℃~+155℃ 100kΩ 100mW 75V Thick Film Resistor ±1% ±100ppm/℃ 0603 Chip Resistor - Surface Mount ROHS | Chip Resistor - Surface Mount | 1.The comment (0603WAF1003T5E) of this part does not match the one (100K) provided in your BOM. Please confirm; | C25803 | https://jlcpcb.com/partdetail/26546-0603WAF1003T5E/C25803 | Basic | 0 | 0 JLCPCB | 0
R14 |  | 42.2K | Resistor_SMD:R_0603_1608Metric |  | Unconfirmed | RC0603FR-0742K2L | YAGEO | 0603 | -55℃~+155℃ 100mW 42.2kΩ 75V Thick Film Resistor ±1% ±100ppm/℃ 0603 Chip Resistor - Surface Mount ROHS | Chip Resistor - Surface Mount | 1.The comment (RC0603FR-0742K2L) of this part does not match the one (42.2K) provided in your BOM. Please confirm; | C273741 | https://jlcpcb.com/partdetail/YAGEO-RC0603FR0742K2L/C273741 | Extended | 0 | 0 JLCPCB | 0
R15 |  | 2.2K | Resistor_SMD:R_0603_1608Metric |  | Unconfirmed | 0603WAF2201T5E | UNI-ROYAL(Uniroyal Elec) | 0603 | -55℃~+155℃ 100mW 2.2kΩ 75V Thick Film Resistor ±1% ±100ppm/℃ 0603 Chip Resistor - Surface Mount ROHS | Chip Resistor - Surface Mount | 1.The comment (0603WAF2201T5E) of this part does not match the one (2.2K) provided in your BOM. Please confirm; | C4190 | https://jlcpcb.com/partdetail/4597-0603WAF2201T5E/C4190 | Basic | 0 | 0 JLCPCB | 0
R16 |  | 0 | Resistor_SMD:R_0603_1608Metric |  | Unconfirmed | 0603WAF0000T5E | UNI-ROYAL(Uniroyal Elec) | 0603 | -55℃~+155℃ 0Ω 100mW 75V Thick Film Resistor ±1% 0603 Chip Resistor - Surface Mount ROHS | Chip Resistor - Surface Mount | 1.The comment (0603WAF0000T5E) of this part does not match the one (0) provided in your BOM. Please confirm; | C21189 | https://jlcpcb.com/partdetail/21903-0603WAF0000T5E/C21189 | Basic | 0 | 0 JLCPCB | 0
R25 |  | 0 | Resistor_SMD:R_0603_1608Metric |  | Unconfirmed | 0603WAF0000T5E | UNI-ROYAL(Uniroyal Elec) | 0603 | -55℃~+155℃ 0Ω 100mW 75V Thick Film Resistor ±1% 0603 Chip Resistor - Surface Mount ROHS | Chip Resistor - Surface Mount | 1.The comment (0603WAF0000T5E) of this part does not match the one (0) provided in your BOM. Please confirm; | C21189 | https://jlcpcb.com/partdetail/21903-0603WAF0000T5E/C21189 | Basic | 0 | 0 JLCPCB | 0
R17 |  | 100 | Resistor_SMD:R_0603_1608Metric_Pad0.98x0.95mm_HandSolder |  | Unconfirmed | 0603WAF1000T5E | UNI-ROYAL(Uniroyal Elec) | 0603 | -55℃~+155℃ 100mW 100Ω 75V Thick Film Resistor ±1% ±100ppm/℃ 0603 Chip Resistor - Surface Mount ROHS | Chip Resistor - Surface Mount | 1.The comment (0603WAF1000T5E) of this part does not match the one (100) provided in your BOM. Please confirm; | C22775 | https://jlcpcb.com/partdetail/23502-0603WAF1000T5E/C22775 | Basic | 0 | 0 JLCPCB | 0
R18 |  | 470 | Resistor_SMD:R_0603_1608Metric_Pad0.98x0.95mm_HandSolder |  | Unconfirmed | 0603WAF4700T5E | UNI-ROYAL(Uniroyal Elec) | 0603 | -55℃~+155℃ 100mW 470Ω 75V Thick Film Resistor ±1% ±100ppm/℃ 0603 Chip Resistor - Surface Mount ROHS | Chip Resistor - Surface Mount | 1.The comment (0603WAF4700T5E) of this part does not match the one (470) provided in your BOM. Please confirm; | C23179 | https://jlcpcb.com/partdetail/23906-0603WAF4700T5E/C23179 | Basic | 0 | 0 JLCPCB | 0
R19 |  | 470 | Resistor_SMD:R_0603_1608Metric_Pad0.98x0.95mm_HandSolder |  | Unconfirmed | 0603WAF4700T5E | UNI-ROYAL(Uniroyal Elec) | 0603 | -55℃~+155℃ 100mW 470Ω 75V Thick Film Resistor ±1% ±100ppm/℃ 0603 Chip Resistor - Surface Mount ROHS | Chip Resistor - Surface Mount | 1.The comment (0603WAF4700T5E) of this part does not match the one (470) provided in your BOM. Please confirm; | C23179 | https://jlcpcb.com/partdetail/23906-0603WAF4700T5E/C23179 | Basic | 0 | 0 JLCPCB | 0
R22 |  | 20K | Resistor_SMD:R_0603_1608Metric |  | Unconfirmed | 0603WAF2002T5E | UNI-ROYAL(Uniroyal Elec) | 0603 | -55℃~+155℃ 100mW 20kΩ 75V Thick Film Resistor ±1% ±100ppm/℃ 0603 Chip Resistor - Surface Mount ROHS | Chip Resistor - Surface Mount | 1.The comment (0603WAF2002T5E) of this part does not match the one (20K) provided in your BOM. Please confirm; | C4184 | https://jlcpcb.com/partdetail/4591-0603WAF2002T5E/C4184 | Basic | 0 | 0 JLCPCB | 0
R23 |  | 0.2 | Resistor_SMD:R_1210_3225Metric |  | Unconfirmed | 1210W2F200LT5E | UNI-ROYAL(Uniroyal Elec) | 1210 | -55℃~+155℃ 200V 200mΩ 500mW Thick Film Resistor ±1% ±800ppm/℃ 1210 Chip Resistor - Surface Mount ROHS | Chip Resistor - Surface Mount | 1.The comment (1210W2F200LT5E) of this part does not match the one (0.2) provided in your BOM. Please confirm; | C52362 | https://jlcpcb.com/partdetail/53376-1210W2F200LT5E/C52362 | Extended | 0 | 0 JLCPCB | 0
R26 |  | 4.7K | Resistor_SMD:R_0603_1608Metric |  | Unconfirmed | 0603WAF4701T5E | UNI-ROYAL(Uniroyal Elec) | 0603 | -55℃~+155℃ 100mW 4.7kΩ 75V Thick Film Resistor ±1% ±100ppm/℃ 0603 Chip Resistor - Surface Mount ROHS | Chip Resistor - Surface Mount | 1.The comment (0603WAF4701T5E) of this part does not match the one (4.7K) provided in your BOM. Please confirm; | C23162 | https://jlcpcb.com/partdetail/23889-0603WAF4701T5E/C23162 | Basic | 0 | 0 JLCPCB | 0
R27 |  | 4.7K | Resistor_SMD:R_0603_1608Metric |  | Unconfirmed | 0603WAF4701T5E | UNI-ROYAL(Uniroyal Elec) | 0603 | -55℃~+155℃ 100mW 4.7kΩ 75V Thick Film Resistor ±1% ±100ppm/℃ 0603 Chip Resistor - Surface Mount ROHS | Chip Resistor - Surface Mount | 1.The comment (0603WAF4701T5E) of this part does not match the one (4.7K) provided in your BOM. Please confirm; | C23162 | https://jlcpcb.com/partdetail/23889-0603WAF4701T5E/C23162 | Basic | 0 | 0 JLCPCB | 0
R28 |  | 120R | Resistor_SMD:R_0603_1608Metric |  | Unconfirmed | 0603WAF1200T5E | UNI-ROYAL(Uniroyal Elec) | 0603 | -55℃~+155℃ 100mW 120Ω 75V Thick Film Resistor ±1% ±100ppm/℃ 0603 Chip Resistor - Surface Mount ROHS | Chip Resistor - Surface Mount | 1.The comment (0603WAF1200T5E) of this part does not match the one (120R) provided in your BOM. Please confirm; | C22787 | https://jlcpcb.com/partdetail/23514-0603WAF1200T5E/C22787 | Basic | 0 | 0 JLCPCB | 0
SW1 |  | SW_Push | Button_Switch_SMD:SW_Tactile_SPST_NO_Straight_CK_PTS636Sx25SMTRLFS |  | Select by System | TS-1101-C-W | XKB Connection | SMD,6x3.6mm | -30℃~+85℃ 12V 2.5mm 2.6N 3.6mm 50,000 Cycles 50mA 6mm No Rectangular Button SPST Surface Mount,Vertical Without Bracket SMD,6x3.6mm Tactile Switches ROHS | Tactile Switches |  | C318938 | https://jlcpcb.com/partdetail/XKBConnection-TS_1101_CW/C318938 | Extended | 21 | 21 JLCPCB | 0.8358
SW2 |  | SW_Push | Button_Switch_SMD:SW_Tactile_SPST_NO_Straight_CK_PTS636Sx25SMTRLFS |  | Select by System | TS-1101-C-W | XKB Connection | SMD,6x3.6mm | -30℃~+85℃ 12V 2.5mm 2.6N 3.6mm 50,000 Cycles 50mA 6mm No Rectangular Button SPST Surface Mount,Vertical Without Bracket SMD,6x3.6mm Tactile Switches ROHS | Tactile Switches |  | C318938 | https://jlcpcb.com/partdetail/XKBConnection-TS_1101_CW/C318938 | Extended | 21 | 21 JLCPCB | 0.8358
SW3 |  | SW_SPDT | Button_Switch_SMD:SW_SPDT_Shouhan_MSK12C02 |  | Select by System | MK-12C02-G025 | G-Switch | SMD,6.6x1.4mm | -20℃~+70℃ 1.4mm 10,000 Cycles 1A 5.2mm 6.6mm 6V Black Rectangular Columnar SPDT Surface Mount, Right Angle SMD,6.6x1.4mm Slide Switches ROHS | Slide Switches |  | C778186 | https://jlcpcb.com/partdetail/GSwitch-MK_12C02G025/C778186 | Extended | 0 | 0 JLCPCB | 0
U1 |  | ESP32-S3-WROOM-1 | RF_Module:ESP32-S3-WROOM-1 |  | Select by System | ESP32-S3-WROOM-1-N4 | Espressif Systems | SMD,25.5x18mm | SMD,25.5x18mm WiFi Modules ROHS | WiFi Modules |  | C2913197 | https://jlcpcb.com/partdetail/3198295-ESP32_S3_WROOM_1N4/C2913197 | Extended | 0 | 0 JLCPCB | 0
U2 |  | MAX485E | Package_SO:SOIC-8_3.9x4.9mm_P1.27mm |  | Select by System | MAX485ED | HTC Korea TAEJIN Tech | SOP-8 | -40℃~+85℃ 1 1 4.75V~5.25V 5Mbps 600uA Half-Duplex Transceiver ±8kV SOP-8 RS-485 / RS-422 ICs ROHS | RS-485 / RS-422 ICs |  | C481667 | https://jlcpcb.com/partdetail/HTC_Korea_TAEJINTech-MAX485ED/C481667 | Extended | 10 | 10 JLCPCB | 3.3
U3 |  | MT3608 | Package_TO_SOT_SMD:SOT-23-6 |  | Select by System | MT3608L | XI'AN Aerosemi Tech | SOT-23-6 | -40℃~+85℃@(TA) 1 1.2MHz 100uA 2.2V~16V 2.5A Adjustable Boost Boost Built-In No SOT-23-6 DC-DC Converters ROHS | DC-DC Converters |  | C2932326 | https://jlcpcb.com/partdetail/XI_AN_AerosemiTech-MT3608L/C2932326 | Extended | 14 | 14 JLCPCB | 0.609
U4 |  | DW01A | Package_TO_SOT_SMD:SOT-23-6 |  | Select by System | DW01A | YONGYUTAI | SOT-23-6 | -40℃~+85℃ 1 1.5V~8V 2.4V 4.3V 4uA Lithium-ion/Polymer Not Supported Protection IC Support SOT-23-6 Battery Management ROHS | Battery Management |  | C2927799 | https://jlcpcb.com/partdetail/YONGYUTAI-DW01A/C2927799 | Extended | 15 | 15 JLCPCB | 0.288
U5 |  | USBLC6-2SC6 | Package_TO_SOT_SMD:SOT-23-6 |  | Select by System | USBLC6-2SC6 | TECH PUBLIC | SOT-23-6 | -55℃~+125℃ 0.35pF 12V 150W 2 5V 6A 6V 80nA ESD IEC 61000-4-2 Unidirectional SOT-23-6 ESD and Surge Protection (TVS/ESD) ROHS | ESD And Surge Protection (TVS/ESD) |  | C2827654 | https://jlcpcb.com/partdetail/TECHPUBLIC-USBLC62SC6/C2827654 | Extended | 14 | 14 JLCPCB | 0.5208
U6 |  | ME6217C33M5 | Package_TO_SOT_SMD:SOT-23-5 |  | Select by System | ME6217C33M5G | MICRONE(Nanjing Micro One Elec) | SOT-23-5 | -40℃~+85℃ 1 100uA 180mV@(300mA) 3.3V 6.5V 65dB@(1kHz) 800mA Fixed Over Temperature Protection Positive SOT-23-5 Voltage Regulators - Linear, Low Drop Out (LDO) Regulators ROHS | Voltage Regulators - Linear, Low Drop Out (LDO) Regulators |  | C427602 | https://jlcpcb.com/partdetail/421842-ME6217C33M5G/C427602 | Extended | 14 | 14 JLCPCB | 0.9982
U7 |  | ME4069-ESOP8 | Package_SO:SOIC-8-1EP_3.9x4.9mm_P1.27mm_EP2.41x3.3mm_ThermalVias |  | Select by System | ME4069ASPG | MICRONE(Nanjing Micro One Elec) | ESOP-8 | -40℃~+85℃ 1 1.8A 1uA 4.2V 4.7V~5.5V Charging IC Lithium-ion/Polymer Support ESOP-8 Battery Management ROHS | Battery Management |  | C494946 | https://jlcpcb.com/partdetail/505878-ME4069ASPG/C494946 | Extended | 10 | 10 JLCPCB | 2.861

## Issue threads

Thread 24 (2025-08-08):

I2C init format incompatible with latest ESP-IDF on ESP32 DevKit

roshanRishantha2004, 2025-08-08:
Description:
The current I2C config code (e.g., dev->cfg.master.clk_speed) is not compatible with the latest ESP-IDF. Will update this to the new i2c_config_t format

roshanRishantha2004, 2025-08-11:
Issue resolved

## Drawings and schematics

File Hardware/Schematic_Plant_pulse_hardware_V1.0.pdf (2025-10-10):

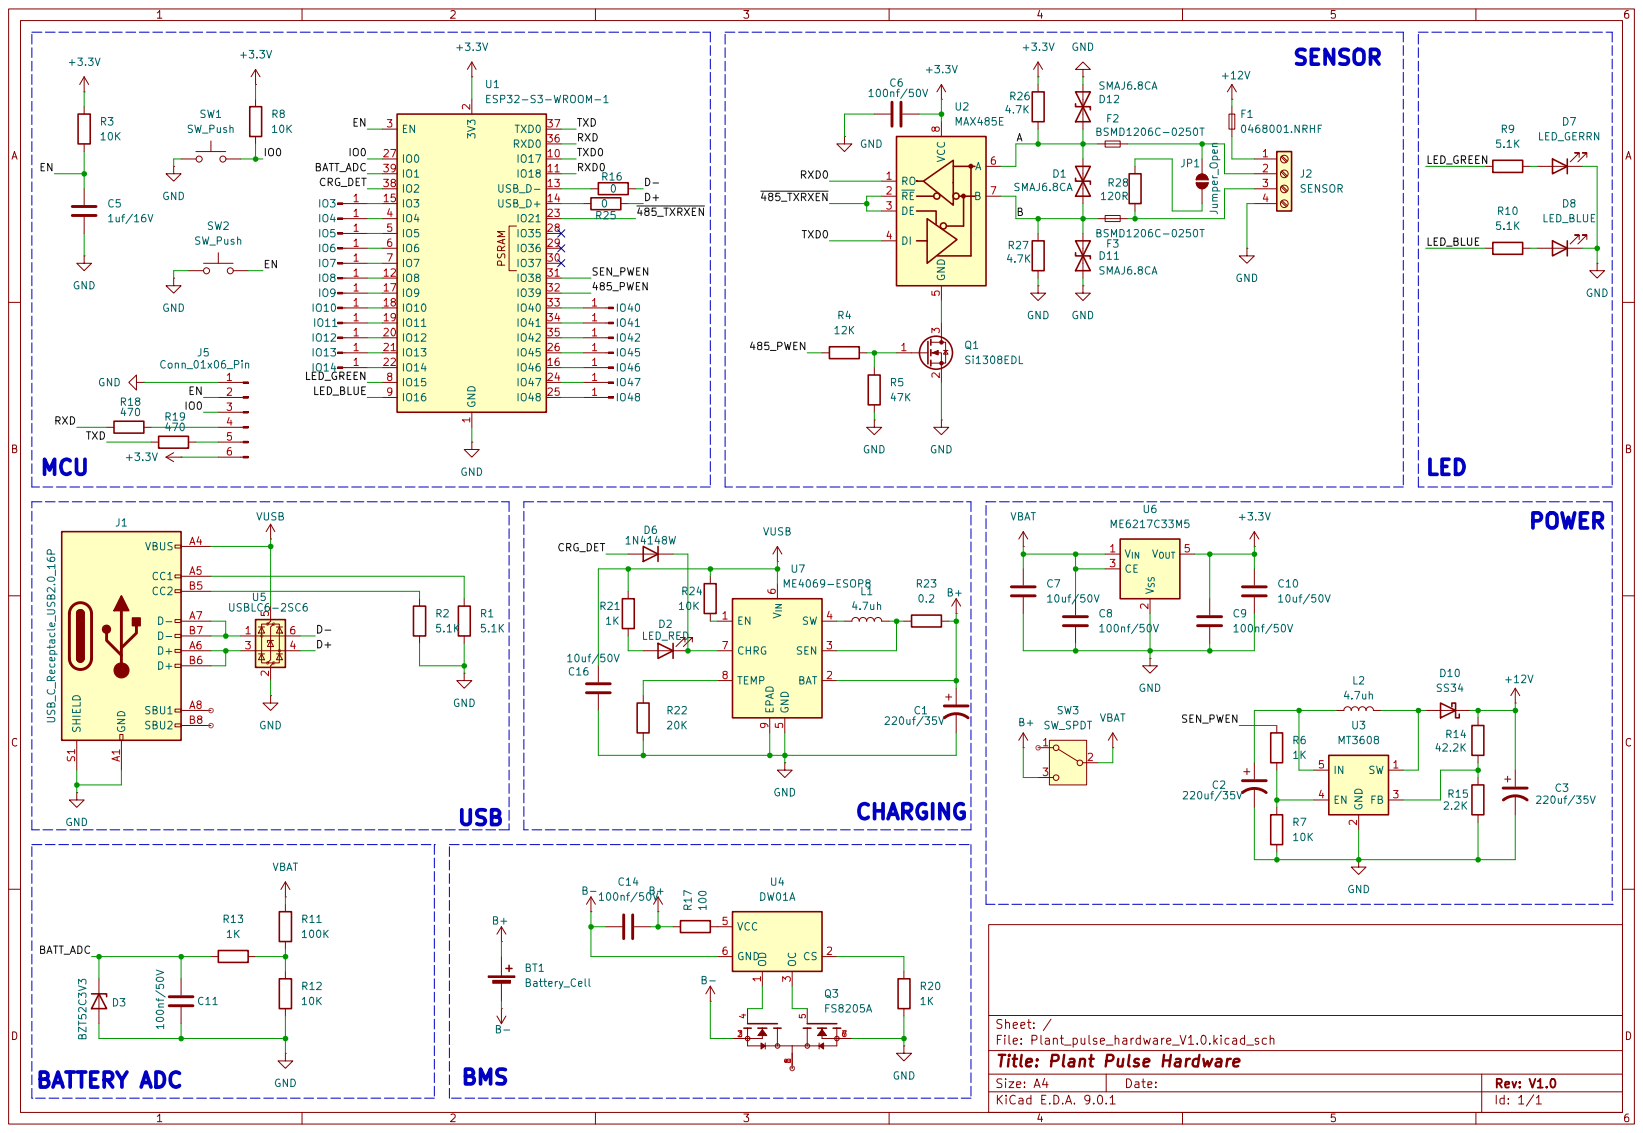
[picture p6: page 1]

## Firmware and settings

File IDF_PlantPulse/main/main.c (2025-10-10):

#include <stdio.h>
#include "freertos/FreeRTOS.h"
#include "freertos/task.h"
#include "esp_sleep.h"
#include "esp_pm.h"
#include "dataLogging.h"
#include "mqtt.h"
#include "storage/FS.h"
#include "myRtc.h"
#include "machinConfig.h"
#include "BLE/ble50_sec_gatts.h"

extern QueueHandle_t modbus_payload_queue;
extern TaskHandle_t dataLoggingTask_Handle;
extern QueueHandle_t mqttAckQueue;
extern TaskHandle_t rtcTask_Handle;
extern TaskHandle_t publishHandleTask_handle;
extern TaskHandle_t connectionHandleTask_handle;
extern TaskHandle_t soilBleTaskHandle;
extern TaskHandle_t pingBleTaskHandle;

extern TaskFunction_t receiveHandleTask_handle;
extern networkState currentStatus;

static void configure_dynamic_frequency(void);
static void reduce_cpu_frequency(void);

void HALT()
{
    while (1)
    {
    }
}

void app_main(void)
{
    configure_dynamic_frequency();
    modbus_payload_queue = xQueueCreate(5, sizeof(M_payload_t));
    mqttAckQueue = xQueueCreate(5, sizeof(char[128])); // Store file paths only

    if (modbus_payload_queue == NULL || mqttAckQueue == NULL)
    {
        ESP_LOGE("modbus_payload_queue", "Failed to create");
        ESP_LOGE("mqttAckQueue", "Failed to create");
        esp_restart();
    }
    if (init_fatfs() == ESP_OK)
    {
        setup_directories();
    }
    else
    {
        ESP_LOGE("FAT", "Failed to mount FATFS");
    }
#if !defined(GSM_DEVICE)
    BLEStart();
#endif
#if defined(GSM_DEVICE)
    isrInit();
    rtcInit();
    initUART();
#endif
    RS_485_Init();
    initTask();
#if defined(GSM_DEVICE)
    struct tm now;
#endif
    // Set time once, then comment this line
    while (1)
    {

        vTaskDelay(pdMS_TO_TICKS(1000));
#if defined(GSM_DEVICE)

        if (currentStatus >= MQTT_STATE_MQTT_CONNECTED)
            checkPendingLogs();
        getTime(&now);
        printf("Time: %02d:%02d:%02d Date: %02d-%02d-%04d\n",
               now.tm_hour, now.tm_min, now.tm_sec,
               now.tm_mday, now.tm_mon + 1, now.tm_year + 1900);
#endif

        // if (sleepEnable == SLEEP)
        // {
        //     reduce_cpu_frequency();
        //     enter_deep_sleep();
        // }
    }
}
void initTask(void)
{
#if defined(GSM_DEVICE)
    xTaskCreatePinnedToCore(connectionHandleTask, "connectionHandleTask", 1024 * 4, NULL, 2, &connectionHandleTask_handle, 0);
    xTaskCreatePinnedToCore(receiveHandleTask, "receiveHandleTask", 1024 * 6, NULL, 5, &receiveHandleTask_handle, 1);
    xTaskCreatePinnedToCore(publishHandleTask, "publishHandleTask", 1024 * 4, NULL, 2, &publishHandleTask_handle, 0);
    xTaskCreatePinnedToCore(dataLoggingHandleTask, "data_collect_task", 1024 * 4, NULL, 2, &dataLoggingTask_Handle, 0);
    xTaskCreatePinnedToCore(rtcTask, "rtcTask", 1024 * 4, NULL, 2, &rtcTask_Handle, 1);
#else
    xTaskCreate(soil_ble_task, "soil_ble_task", 4096, NULL, 5, &soilBleTaskHandle);
    xTaskCreate(ping_ble_task, "ping_ble_task", 4096, NULL, 5, &pingBleTaskHandle);

#endif
}

static void configure_dynamic_frequency(void)
{
    esp_pm_config_esp32s3_t pm_config = {
        .max_freq_mhz = 240,        // Maximum frequency
        .min_freq_mhz = 80,         // Minimum frequency
        .light_sleep_enable = false // Keep in active mode
    };
    esp_err_t ret = esp_pm_configure(&pm_config);
    if (ret == ESP_OK)
    {
        ESP_LOGI("Frequency", "Dynamic CPU frequency scaling configured.");
    }
    else
    {
        ESP_LOGE("Frequency", "Failed to configure CPU frequency: %s", esp_err_to_name(ret));
    }
}

static void reduce_cpu_frequency(void)
{
    // ESP_LOGE("Frequency", "delete all task");
    esp_pm_dump_locks(stdout);

    // Delete all tasks except the current one
    vTaskDelay(pdMS_TO_TICKS(100)); // Allow time for tasks to clean
    vTaskSuspendAll();
    esp_pm_config_esp32s3_t pm_config = {
        .max_freq_mhz = 80, // Set both min and max to 80 MHz to reduce power
        .min_freq_mhz = 4,
        .light_sleep_enable = false};
    esp_err_t ret = esp_pm_configure(&pm_config);
    vTaskDelay(pdMS_TO_TICKS(10)); // Allow time for frequency update

    if (ret == ESP_OK)
    {
        // ESP_LOGI("Frequency", "Dynamic CPU frequency scaling configured.");
    }
    else
    {
        // ESP_LOGE("Frequency", "Failed to configure CPU frequency: %s", esp_err_to_name(ret));
    }
    esp_pm_dump_locks(stdout);
    //int cpu_freq_mhz = esp_clk_cpu_freq() / 1000000;
   // ESP_LOGI("CPU Monitor", "Current CPU frequency: %d MHz", cpu_freq_mhz);
    // HALT
}

static void enter_deep_sleep(void)
{
    ESP_LOGI("DEEP_SLEEP", "Going to deep sleep...");
// gpio_pullup_en(PIR);  // Enable pull-up resistor
#if defined(GSM_DEVICE)
    esp_sleep_enable_ext0_wakeup(INT_PIN, 0); // Wake-up when button is pressed (LOW)
#endif
    // Enter deep sleep
    esp_deep_sleep_start();
}

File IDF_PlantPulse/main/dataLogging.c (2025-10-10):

#include <string.h>
#include "dataLogging.h"

QueueHandle_t modbus_payload_queue;
TaskHandle_t dataLoggingTask_Handle = NULL;
TaskHandle_t soilBleTaskHandle = NULL;
TaskHandle_t pingBleTaskHandle = NULL;



M_payload_t build_modbus_payload(void)
{
    M_payload_t payload;
    memset(&payload, 0, sizeof(payload));

    // 1. Timestamp (Unix or custom function)
    // payload.timestamp = get_unix_timestamp();  // e.g., from RTC task

    // 2. Device ID (6 bytes)
    // get_device_id(payload.device_id);  // e.g., ESP32 MAC address

    // 3. Topic (max 20 bytes)
    // strncpy(payload.topic, "sensor/data", sizeof(payload.topic));

    // 4. Battery level (mV)
    // payload.battery_mv = get_battery_mv();  // Your custom ADC read

    // 5. Read all 20 Modbus sensors
    for (int i = 0; i < SENSOR_COUNT; i++)
    {
        uint8_t slave_id = SENSOR_SLAVE_START + i;
        uint8_t tx_buf[8] = {0};
        uint8_t rx_buf[64] = {0};
        bool success = false;

        // turn on the sensor here

        for (int attempt = 0; attempt < 5; attempt++)
        {
            MB_rtu_send(slave_id, SOIL8IN1_FUNC_CODE, SOIL8IN1_REG_ADDR, SOIL8IN1_REG_COUNT, tx_buf, 0);
            int recv_len = MB_rtu_receive(rx_buf, sizeof(rx_buf));

            int expected_len = 5 + SOIL8IN1_REG_COUNT * 2; // 1 addr + 1 func + 1 byteCount + 2*reg + 2 CRC
            if (recv_len >= expected_len)
            {
                uint16_t recv_crc = (rx_buf[recv_len - 2]) | (rx_buf[recv_len - 1] << 8);
                uint16_t calc_crc = crc16(rx_buf, recv_len - 2);

                if (recv_crc != calc_crc)
                {
                    ESP_LOGW("MODBUS", "CRC mismatch from Sensor ID %d (attempt %d)", slave_id, attempt + 1);
                    continue;
                }

                // Parse 7 values: pH, moisture, temperature, ec, N, P, K
                payload.sensor_data[i].ph = (rx_buf[3] << 8) | rx_buf[4];
                payload.sensor_data[i].moisture = (rx_buf[5] << 8) | rx_buf[6];
                payload.sensor_data[i].temperature = (int16_t)((rx_buf[7] << 8) | rx_buf[8]);
                payload.sensor_data[i].conductivity = (rx_buf[9] << 8) | rx_buf[10];
                payload.sensor_data[i].nitrogen = (rx_buf[11] << 8) | rx_buf[12];
                payload.sensor_data[i].phosphorus = (rx_buf[13] << 8) | rx_buf[14];
                payload.sensor_data[i].potassium = (rx_buf[15] << 8) | rx_buf[16];

                success = true;
                break;
            }
            else
            {
                ESP_LOGW("MODBUS", "Sensor ID %d response error (attempt %d)", slave_id, attempt + 1);
            }
            vTaskDelay(pdMS_TO_TICKS(100));
        }

        if (!success)
        {
            memset(&payload.sensor_data[i], 0xFF, sizeof(payload.sensor_data[i]));
            ESP_LOGW("MODBUS", "Sensor ID %d failed after 5 attempts", slave_id);
        }
    }

    // 6. Reserved bytes (4 bytes can be any future use)
    payload.reserved[0] = 0xFF;
    payload.reserved[1] = 0xFF;
    payload.reserved[2] = 0xFF;
    payload.reserved[3] = 0xFF;

    // 7. CRC (over the whole payload except this CRC field)
    payload.crc = crc16((uint8_t *)&payload, sizeof(payload) - 2);

    return payload;
}

void dataLoggingHandleTask(void *pvParameters)
{
    M_payload_t payload;

    while (1)
    {
        // Wait for notification from RTC or triggering task
        ulTaskNotifyTake(pdTRUE, portMAX_DELAY);

        // ESP_LOGI("MODBUS_TASK", "Collecting Modbus data...");
        payload = build_modbus_payload();

        //-------------------dammy data------------------------------------------------------

        ESP_LOGI("MODBUS_TASK", "Collecting dummy Modbus data...");
        // --- Fill timestamp ---
        payload.timestamp = esp_timer_get_time(); // microseconds since boot
        // --- Dummy device ID (can use MAC in future) ---
        uint8_t dummy_mac[6] = {0xAA, 0xBB, 0xCC, 0x11, 0x22, 0x33};
        memcpy(payload.device_id, dummy_mac, 6);
        // --- Topic ---
        strncpy(payload.topic, "soil/sensor", sizeof(payload.topic));
        // --- Dummy battery voltage ---
        payload.battery_mv = 3700;
        // --- Dummy data for 20 sensors ---
        for (int i = 0; i < 1; i++)
        {
            payload.sensor_data[i].ph = 700 + i; // e.g., pH = 7.00
            payload.sensor_data[i].moisture = 350 + i;
            payload.sensor_data[i].temperature = 250 + i; // e.g., 25.0°C
            payload.sensor_data[i].conductivity = 500 + i;
            payload.sensor_data[i].nitrogen = 20 + i;
            payload.sensor_data[i].phosphorus = 10 + i;
            payload.sensor_data[i].potassium = 30 + i;
        }
        // --- Reserved ---
        memset(payload.reserved, 0xFF, sizeof(payload.reserved));
        // --- CRC ---
        payload.crc = crc16((uint8_t *)&payload, sizeof(M_payload_t) - sizeof(payload.crc));
        //------------------dummy end--------------------------------------------------------

        if (xQueueSend(modbus_payload_queue, &payload, pdMS_TO_TICKS(100)) != pdPASS)
        {
            ESP_LOGW("MODBUS_TASK", "Failed to queue Modbus payload");
        }
        else
        {
            ESP_LOGI("MODBUS_TASK", "Modbus payload queued for MQTT");
        }
    }
}
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

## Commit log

2025-05-07 add 7 in 1 Soil Sensor Datasheet
2025-07-25 solved mqtt rcv ping & data #16
    [dataLogging.c, dataLogging.h, main.c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]
2025-07-25 done #18
    [partitions.csv]
2025-08-08 add file system
    [partitions.csv]
2025-08-11 issuse resolved:i2c driver issue
    [ds3231.c, rtc_api.c]
2025-08-29 add rtc and working with fatfs
    [partitions.csv]
2025-09-23 Create UI Wireframe
2025-10-10 V1.0 Gerber, Schematic, BOM, POS
    [Plant_pulse_hardware_V1-B_Cu.gbr, Plant_pulse_hardware_V1-B_Fab.gbr, Plant_pulse_hardware_V1-B_Mask.gbr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]
2025-10-10 Add functions for device ID, RSSI, battery, and charge status in ping packet
